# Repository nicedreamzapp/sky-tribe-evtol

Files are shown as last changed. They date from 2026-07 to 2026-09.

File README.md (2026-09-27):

# Sky Tribe — Open Amphibious Personal eVTOL
*A single-seat electric flying machine that lands on water and takes off again. Designed and built in America, given away to everyone.*

**In one sentence:** Sky Tribe is an open-source design for a one-person electric VTOL aircraft that floats, with an interactive 3D CAD viewer and runnable Node scripts that check its geometry, performance and cost.

**Stage:** design and analysis. Nothing has been built or flown yet; the first hardware step (M1, one motor on a thrust stand) is still ahead.

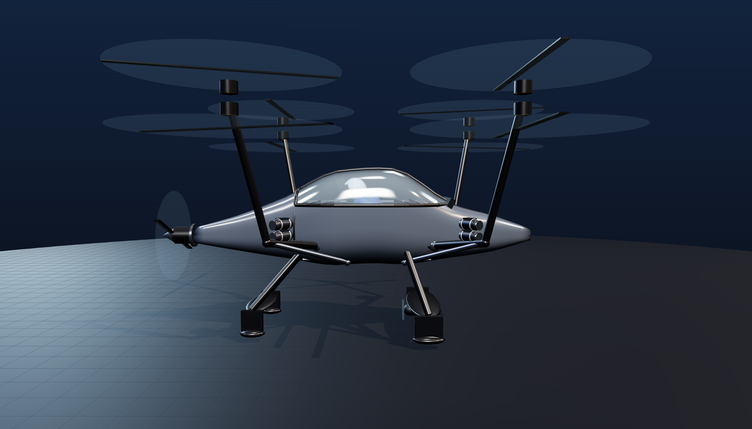
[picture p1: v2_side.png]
Sky Tribe P1 — side


> **Mission:** This project is about freedom of movement, not force. Quiet electric flight. Fewer barriers between people and places. A machine that treats the ocean as a friend — never a weapon. We build it to unite, to explore, and to give people more free will in how they move through the world.

| | |
|---|---|
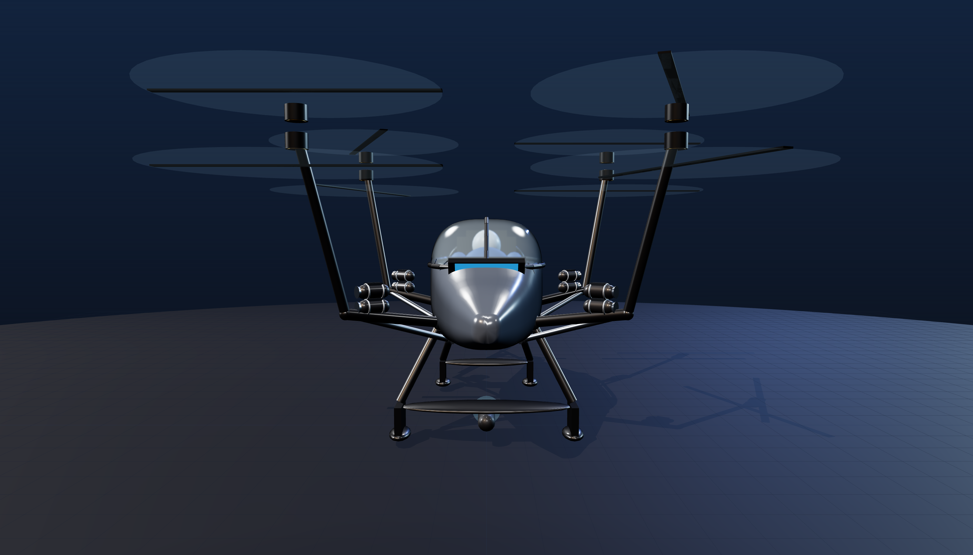
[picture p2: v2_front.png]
front
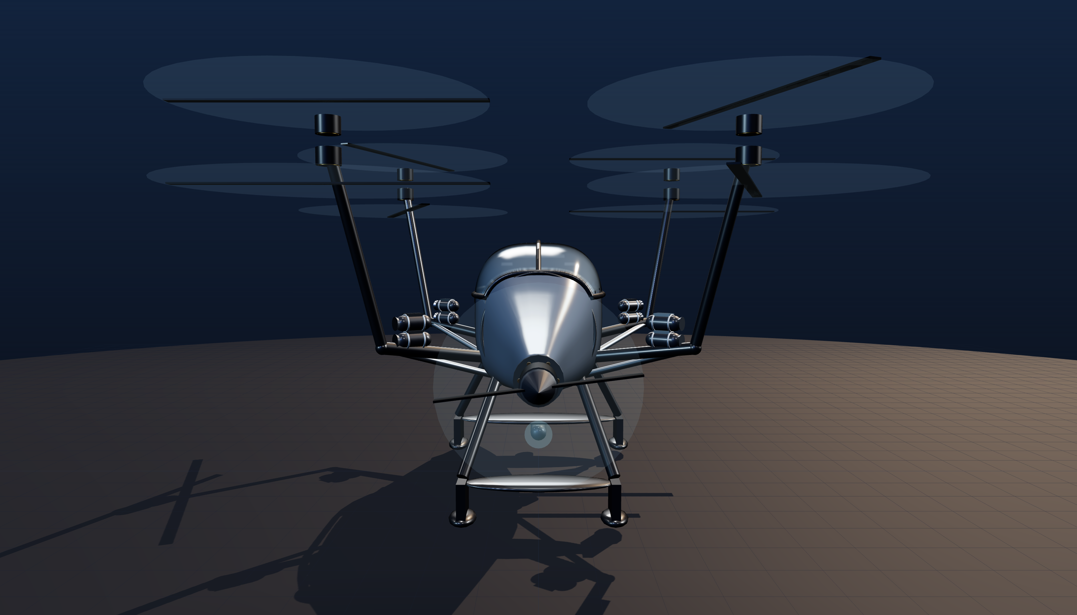
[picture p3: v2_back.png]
back
|  |  |

**Proof you can run in a minute** (Node.js only, no npm install):
```bash
node geometry_audit.mjs     # 19 clearance checks, 0 FAIL, 0 WARN
node performance_model.mjs  # hover, endurance and range for P1 and P2
node project_cost.mjs       # parts, hidden costs, whole-program total
```
Then open `sky_tribe_viewer.html` in a browser to spin the CAD.

## What I built (Matt Macosko)
- **Interactive CAD viewer:** [`sky_tribe_viewer.html`](sky_tribe_viewer.html), with P1 / P2 / P3 configs, click-a-part price and spec cards, a narrated tour (`?present=1`) and PNG export (`?shot=1`). Shortcuts: [`sky_tribe_P1_heavy.html`](sky_tribe_P1_heavy.html), [`sky_tribe_P2_light.html`](sky_tribe_P2_light.html)
- **Geometry audits:** [`geometry_audit.mjs`](geometry_audit.mjs) (+ [`geometry_audit.html`](geometry_audit.html)), [`interior_audit.mjs`](interior_audit.mjs), [`hybrid_audit.mjs`](hybrid_audit.mjs)
- **Performance model:** [`performance_model.mjs`](performance_model.mjs) (hover power, max endurance, best-range speed)
- **Hybrid genset analysis:** [`hybrid_energy_model.mjs`](hybrid_energy_model.mjs), [`hybrid_bom.mjs`](hybrid_bom.mjs)
- **Cost and build order:** [`project_cost.mjs`](project_cost.mjs), [`build_order.mjs`](build_order.mjs), [`PARTS_LIST_BOM.md`](PARTS_LIST_BOM.md)
- **Research:** five rounds in [`RESEARCH_REPORT_*.md`](RESEARCH_REPORT_2026-07-13.md), plus [`WATER_STANCE.md`](WATER_STANCE.md)
- **Design history:** OpenSCAD models [`manned_quad_v2.scad`](manned_quad_v2.scad) through [`manned_quad_v7.scad`](manned_quad_v7.scad)

Upstream: 3D rendering uses [three.js](https://threejs.org/) (loaded from a CDN). The planned flight stack is upstream [ArduPilot](https://ardupilot.org/) / [PX4](https://px4.io/); see [`CREDITS.md`](CREDITS.md).

## What this is
A fully open-source design for a **single-seat coaxial-X8 electric VTOL** — eight motors on four arms — that is sealed and buoyant so it can **land on water and take off again**, like the waterproof RC drones, scaled up to carry one person.

Everything is open: the CAD, the parts list, the flight-control approach, and the research behind every decision. No proprietary black boxes. If someone already gave their work away (open-source flight software, published physics), we build on it and give ours away too.

**Every number below is one we can defend, including the ones that hurt.**

## Two aircraft, one airframe
The weight limit was blocking everything, so we stopped letting it. Same airframe, same X8, same quick-swap battery bay — two configurations in two different legal lanes.

| | **P1 — "the fat crazy one"** | **P2 — "the low-cost lightweight one"** |
|---|---|---|
| Empty | ~176 kg | ~124 kg |
| Battery | 13 kWh · 58 kg | 5 kWh · 20 kg |
| Endurance | **11.9 min hover · 15.1 min max** | **6.4 min hover · 7.9 min max** |
| Range | ~15 miles (at 73 mph) | ~6.6 miles (at 60 mph) |
| Speed | best-range 73 mph · level cruise (pusher) | best-range 60 mph · cruises 9–13° nose-down |
| Legal lane | Experimental amateur-built (N-number, licensed pilot) | **Part 103 ultralight** — no licence, no registration |
| Purpose | The learning machine. Flies first. Weight is not a constraint. | The production seed. Built with P1's lessons. |

P1 exists so the program isn't hostage to the 254 lb limit. P2 is the machine anyone can legally fly.

## Current design
- **Propulsion:** coaxial **X8** — 8 motors, 4 arms, 2× 62" counter-rotating props per arm, ~33 kg/m² disk loading
- **Why X8:** a flat quad has **no motor-out capability** — one dead motor or ESC and it is uncontrollable. The literature is blunt about it: a single-rotor failure on a manned quad is catastrophic, quads show the highest failure rate of the configurations studied, and **at least eight rotors** is what satisfies motor-out safety. A standard hexacopter is *not* fault-tolerant either — six rotors buys nothing.
- **Structure:** central carbon spar box carries all four arms, the seat and the gear. Booms **dog-leg outboard low, then climb** — nothing crosses the canopy. Each boom is braced from *below* by a keel strut, like a braced-wing aircraft's lift strut.
- **Flight control:** DIY triple-redundant, built on open-source **ArduPilot/PX4** across 3 voting boards — not an $18k proprietary box. This is the plan; the voting code is not in this repo yet.
- **Water:** sealed buoyant hull (**650 L against 261 L displaced — 2.5× reserve**), motors high, floats then flies. Never powers up through the surface.
- **Safety:** whole-aircraft ballistic parachute (Part 103 weight-exempt)

## Honest status — what does not close yet
- **Hover draws ~52 kW at P1's 261 kg all-up**, not the ~25 kW quoted early on. That figure was for a lighter quad, ignored the 9–15% coax penalty, and quoted shaft power rather than what the battery actually pays.
- **Endurance is the real problem, not speed.** P1 flies **15 minutes** and **15 miles**; P2 flies **8 minutes** and **6.6 miles**. These are hop-across-the-bay machines, not tourers.
- **Top speed is capped by the rotors, not power.** Past roughly **67 mph** (advance ratio 0.25) the advancing blade runs out of tip margin while the retreating blade loses grip. A pusher does *not* raise that ceiling — it buys a level cruise attitude and better efficiency, nothing more.
- **A genset roughly quadruples the endurance** — 5 gallons of petrol is 172 kWh thermal ≈ 43 kWh electrical, against 13 kWh in the battery, and under Part 103 *fuel is weight-exempt while batteries are not*. That is **49 minutes of hover against 12**. It costs **+$2,500 and +34 kg**: the full system is 92 kg (engine 42, generator 7, radiator 14, buffer 10, plus rectifier, mounts, exhaust and fuel system) versus 58 kg of battery. All-up rises to 309 kg, which needs **70 kg/motor** to fly — so the genset does not dodge M1, it leans on it harder. See `hybrid_bom.mjs`.
- **Thrust-to-weight is the live risk.** At 50 kg/motor P1 is only 1.35 — and 1.18 with a motor out. It needs **60–70 kg/motor**. **M1 (thrust-standing one motor) is the gate that decides whether P1 flies at all.**
- **P2 is ~9 kg over** the 115.2 kg Part 103 limit as drawn. The carbon layup has to close that gap.
- **Foiling doesn't close.** It floats and flies off water today — that part is sound. But the water pod is under-powered for the takeoff hump (~2.2 kW needed, ~2 kW modelled) and the foil is not yet a real cambered section. Foiling is Phase 2.
- **No flight-control code, test data or hardware exists yet.** Everything here is CAD, models and research.
- Jetson ONE proves 253 lb *is* achievable, so the P2 target is real.

## What it costs — honestly
The parts list is not the project. Both numbers matter, and they are far apart.

| | |
|---|---|
| **P1 — one aircraft, parts only** | **~$46,600** (up to ~$53,800 if the motors land at U15XXL-class) |
| P2 — lighter build, smaller pack, no pusher | ~$39,600 |
| P3 — same airframe, battery swapped for the genset | ~$49,100 |
| **P1 actually flying, all in** | **~$82,600** |
| Whole program (P1 + P2 + genset conversion) | ~$139,700 |

The gap between $46,600 and $82,600 is everything a parts list quietly omits: the
thrust stand, tether rig and ballast; carbon moulds, vacuum and consumables;
machining the spar box; wiring and HV safety gear; telemetry; spares; and an
**$8,000 crash allowance**, because M2 and M3 exist precisely to break things.
Labour is $0 — it assumes you build it yourself.

**The cheapest useful thing you can do is ~$5,300**: one motor, one prop, one ESC and
a thrust stand. That is M1, and it answers whether any of this flies before the big
money moves. Vendor numbers die on the stand. See `project_cost.mjs`.

### You do not build the cockpit first
The ladder already says M2 and M3 are unmanned and ballasted — so nothing that exists
for a *person* is needed to prove the machine hovers:

| | | |
|---|---|---|
| **Step 1 — M1** | one motor on a stand | **~$5,300** |
| **Step 2 — M2/M3** | a flying platform: spar box, arms, 8 motors, props, ESCs, battery, computers, plain test skids, tether | **~$33,300** |
| **Step 3 — M4/M5** | everything a human needs: tub, canopy, seat, panel, chute, foil gear, pusher | **~$18,100** |

The cockpit, the canopy, the parachute and the hydrofoil gear are **$18,100 you can
defer** until the aircraft has already hovered thousands of times. Build the platform.
Fly it empty. Add the human last — which is exactly what the safety ladder demanded
anyway. See `build_order.mjs`.

## Safety comes before any human ever flies it
**No person goes aboard until this is proven safe** — unmanned first, then ballasted, across many loads and conditions. The build order is non-negotiable:

1. **M0** — Close the weight budget on paper
2. **M1** — Thrust-stand ONE motor. **Vendor numbers die on the stand.**
3. **M2** — Full frame, tethered unmanned hover
4. **M3** — Ballasted tethered hover, thousands of cycles
5. **M4** — Manned, tethered, over water
6. **M5** — Free flight over water

## Geometry is audited, not eyeballed
`geometry_audit.mjs` checks the whole craft numerically — every boom and strut sampled along its length against the canopy, prop and rotor clearances, the coax spacing rule, gear-to-ground, pilot sightlines and headroom, battery fit at its **actual height**, and pusher clearances.

```bash
node geometry_audit.mjs     # 19 checks, 0 FAIL, 0 WARN
```

It exists because eyeballing kept missing real defects: arms passing through the canopy glass, a battery hanging out through the belly, the pilot's feet outside the fuselage, and a cockpit sill sitting *above* the pilot's eye line.

## Repository map
| File | What it is |
|---|---|
| `sky_tribe_viewer.html` | **The live CAD.** Interactive, photoreal, click any part for its price and spec |
| `sky_tribe_P1_heavy.html` / `sky_tribe_P2_light.html` | Open the CAD locked to either configuration |
| `geometry_audit.mjs` / `geometry_audit.html` | Automated clearance + interference audit |
| `interior_audit.mjs` / `hybrid_audit.mjs` | Cockpit parts and genset hardware fit inside the skin |
| `performance_model.mjs` / `hybrid_energy_model.mjs` | Hover, endurance, range; what fuel is worth |
| `project_cost.mjs` / `build_order.mjs` / `hybrid_bom.mjs` | Cost, staged spend, genset parts and mass |
| `PARTS_LIST_BOM.md` | Bill of materials (**being refreshed for the X8**) |
| `RESEARCH_REPORT_*.md` | Five rounds of fact-checked research, adversarially verified |
| `manned_quad_v2..v7.scad` | Design history (superseded by the viewer) |

**View the CAD:** open `sky_tribe_viewer.html` in any browser — no install, no account. It needs an internet connection, because three.js loads from unpkg.
`?cfg=p1|p2|p3` picks a configuration · `?present=1` runs a narrated tour · `?shot=1` renders a PNG

## How to contribute
Anyone may use, study, modify, and share this design. Improvements that keep it open are welcome — especially the weight budget, the redundant flight-control code, water sealing at scale, and the foil section. **Test data is as valuable as design changes.** No weapons work.

## License
Open hardware and open source, chosen so it can **never be locked up**:
- **Hardware / CAD:** [CERN-OHL-S-2.0](https://ohwr.org/cern_ohl_s_v2.txt) (strongly reciprocal — derivatives stay open)
- **Software:** [GPL-3.0](https://www.gnu.org/licenses/gpl-3.0.txt)
- **Documentation / research:** [CC-BY-SA-4.0](https://creativecommons.org/licenses/by-sa/4.0/)

You are free to build one. You are not free to take it private.

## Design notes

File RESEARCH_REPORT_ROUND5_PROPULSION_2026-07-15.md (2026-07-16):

# Sky Tribe — Round 5 Research: Propulsion & Architecture (no taboos)
**Date:** 2026-07-15 · **Method:** deep-research harness, 104 agents, 22 sources fetched, 107 claims extracted, 25 verified by 3-vote adversarial panel → **24 confirmed, 1 refuted**

## The one-line verdict
**Electric multirotor is confirmed #1 — we're on the right propulsion. But the flat quad was the weakest link in the whole design, and the X8 decision (made 2026-07-15) is now literature-backed, not just instinct.**

---

## 1. Architecture — the X8 call was RIGHT (and hexa is a trap)

- **A manned flat quad is ruled out by the numbers** (DLR HorizonUAM, verified verbatim): single-rotor failure on a quad is *catastrophic* — partial lift loss is uncontrollable for a passenger vehicle. Quads showed the **highest catastrophic failure rate of four VTOL configs studied (~8×10⁻⁴/hr)**. Studies conclude **at least eight rotors (coax X8 or flat octo)** is what actually satisfies motor-out safety. Motor-out on a quad-shaped layout also demands ~2× installed power (each corner sized for ≥50% of hover thrust). *Caveat: those reliability budgets are air-taxi certification stringency, way beyond Part 103 — but the physics of "dead corner = uncontrollable" applies to any manned quad.*
- **Hexacopter is NOT a middle path** (Du/Quan, AIAA JGCD 2015, verified): the standard alternating-spin hexa is **uncontrollable after ANY single rotor failure** despite having six motors. Even the special fault-tolerant spin arrangement still has two unsurvivable rotor positions. **Motor-out survival depends on spin-direction geometry, not rotor count.** Six motors ≠ redundancy.

## 2. Honest correction: the coax penalty is BIGGER than we assumed

We budgeted ~5–8% for the X8's stacked-rotor loss. **The verified number is ~9–15% for an optimized design** (NASA Ames CFD: a coax pair gives 182% of one rotor, not 200%; bench tests: ~14% thrust-per-watt penalty, up to 19–23% on the worst metric). Key details:
- The loss falls almost entirely on the **lower rotor** (~64% of its isolated thrust — it drinks the top rotor's downwash).
- A **stopped lower rotor adds ~180 gf of backwash drag** — relevant to motor-out thrust math.
- Mitigations: **graded/higher pitch on the lower prop**, and the penalty **shrinks at higher disk loading**.
- Literature is admittedly messy at small scale (13–28" props); direction transfers to our 54" props, exact percentages don't.

**Design rules that survived verification:**
- **Coax vertical spacing ≥ 0.25 rotor diameters** — thrust is nearly insensitive to spacing above that; below it you pay. For 54" props that's ≥ ~343 mm between the two prop planes. *(CAD updated to 350 mm same day.)*
- **Small prop-disc overlap (0–20%) with vertical offset is harmless to slightly beneficial** (+1–2% thrust at constant power) — arm geometry has slack if we ever tighten the footprint.
- The NASA Ames / Army AFDD hover-chamber dataset (coax/tandem/tilt vs equal-solidity single rotors) is the apples-to-apples benchmark to design against.

**BOM implication:** X8 needs ~9–15% more battery for equal endurance vs the quad, not 5–8%. Fold into the next BOM refresh.

## 3. Propulsion ranking (verified where possible)

1. **Distributed electric multirotor — CONFIRMED #1.** Nothing that survived verification beats it at 25 kW / Part 103 scale. We're using it.
2. **Series-hybrid genset — right idea, HARDWARE GAP FOUND.** The Part 103 fuel exemption genuinely favors fuel over batteries (14 CFR 103.1 verified: fuel excluded, 5 US gal cap, batteries count). **But no off-the-shelf genset fits our ~25–30 kW floor in 2026:**
   - Pegasus GE70: **4 kW peak / 3.5 kg** — drone-scale, 6–9× too small, and it's Pegasus's *largest* unit.
   - Turbotech TG-R90 turbogenerator: **85 kW / 64 kg dry**, multi-fuel incl. H2 (bench-demo'd w/ Safran 2024), flight-proven on experimental eVTOLs — but 3× oversized and eats 56% of our entire empty-weight budget.
   - **The 20–40 kW middle is an empty market in 2026.** Options: recheck for new entrants before the hybrid trade study; consider paralleling smaller units; or accept the 1-hr config waits for the market to fill in.
3. **Micro-turbine direct drive / H2 fuel cells / everything else** — nothing at our scale survived verification this round (see coverage caveats).

## 4. Exotics — the physics gate held

| Concept | Verdict | Why |
|---|---|---|
| EHD / ionic wind hover | **CLOSED** | Verified trade-off (MIT/Barrett, Proc. R. Soc. A): thrust density and efficiency trade against each other — the famous ~100 N/kW exists only at ~1–3 N/m², orders of magnitude below the ~200–500 N/m² a hovering manned craft needs. Newer ducted multi-stage work pushed density ~10× (our older "750 m² needed" number was REFUTED — killed 1-2 in verification) but it's still tens of N/m². Closed for hover; interesting for near-silent fixed-wing cruise someday. |
| Static maglev / "hover on Earth's field" | **CLOSED** | Earnshaw's theorem: no static arrangement of magnets/charges can stably levitate. Earth's ~50 µT field has nothing usable to push against for free flight. |
| Beamed power hover | **FRONTIER, far off** | Best 2025 demo (DARPA POWER/PRAD): **800 W at 8.6 km for 30 seconds** — a record, and still ~30× short of our hover floor, delivered for 1/120th of our minimum flight. Watch, don't build. |
| Tesla-lineage | Same as beamed power — resonant/wireless transmission is his real legacy and it's the row above. No verified antigravity anything. |

## 5. Coverage caveats (what this round did NOT confirm)
Nothing survived verification on: real-program rationales (Jetson ONE 8-motor layout, LIFT Hexa's 18 rotors — extracted but not confirmed), fuselage aero critique (fineness ratio, tail cone, spray ingestion), H2 stacks at our scale, variable-pitch/rim-driven/cycloidal rotors, flywheels, ground effect. **Treat those as open, not settled.** Two claims passed 2-1 (coax equal-throttle loss; GE70 power density) — verified against primaries but carry metric-mismatch caveats.

## 6. Open questions for Round 6
1. Actual coax penalty at OUR scale (62"→54" props, our disk loading, graded-pitch lower rotors) — full-scale test or validated CFD decides 9% vs 15%.
2. Can the 115.2 kg budget absorb the X8 conversion + 9–15% bigger battery? (Two-prototype program partially defuses this — P1 heavy doesn't care.)
3. Does ANY 20–40 kW genset ship in 2026? Recheck before committing the hybrid trade study.
4. The unverified areas above need their own pass — especially water ops (spray ingestion at our rotor height) before M5.

## Key sources (all fetched & verified 2026-07-15)
- DLR HorizonUAM powertrain reliability: arxiv.org/pdf/2309.10631
- Hexa controllability (Du/Quan): arxiv.org/pdf/1403.5986
- NASA Ames coax CFD (Yoon 2017): ntrs.nasa.gov/api/citations/20170000654
- Rutgers coax experiments (Aerospace 2022): mdpi.com/2226-4310/9/8/452
- Overlap/offset (Weishaupl & Prior): eprints.soton.ac.uk/433170
- Pegasus GE70: pegasusaero.ca/ge70 · Turbotech TG-R90: turbotech-aero.com/solutions
- EHD trade-off (Masuyama & Barrett): royalsocietypublishing.org (Proc. R. Soc. A 2015)
- DARPA power-beaming record: darpa.mil/news/2025 · Earnshaw: math.ucr.edu/home/baez
- Part 103 text: ecfr.gov 14 CFR 103 · FAA: faa.gov/media/13046

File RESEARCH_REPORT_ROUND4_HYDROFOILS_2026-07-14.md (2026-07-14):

# Round 4 — Hydrofoil Landing Gear (foil = skid)
**Date:** July 14, 2026 · 101-agent sweep, 3-vote verification. Permanent reference for sizing our foils.

## Bottom line
Foiling a ~240 kg single-seat amphibian is **physically feasible with real prior art.** The smart choice for our weight is **fixed inverted-V surface-piercing foils** (self-balancing, no computer needed). The hard part isn't lift — it's the **takeoff "hump"** (needs ~3–4× the cruise power). And the one piece nobody has proven is **exactly your idea**: a foil strut that ends in a skid foot for hard-ground landing. That's our open ground.

## The sizing math (verified)
Lift: **L = ½ · ρ · V² · S · C_L** (ρ_water = 1000, so water makes huge lift). Worked check: 0.12 m² at C_L 0.60 and 6 m/s (~12 knots) in fresh water = **~1,300 N ≈ 132 kg**. So to lift our **240 kg we need ~0.15–0.20 m² of total foil area** at ~15 knots — small.
- **Real anchor:** a 650 kg ultralight seaplane (SEAGULL, peer-reviewed) used 0.2 m²/foil at 15 knots. Scaled to us ≈ **~0.07–0.10 m² per foil** (two foils). Foils cut its liftoff speed from 44 → ~20 knots and unloaded the hull by ~80%.
- **Minimum foiling speed: ~15–18 knots (17–21 mph).** Below that, the wings don't make enough lift and you sit as a hull.

## How it balances — this answers your question directly
Two proven paths:
1. **Fixed inverted-V surface-piercing foils (LISA Akoya "Seafoils")** — **self-stabilizing with ZERO pilot input and no controller.** As the craft rises, less foil is in the water, so lift drops automatically — it self-levels. Flew at Oshkosh 2012. **This is the best architecture for our Part 103 weight budget** — no actuators, no computer loop, lightest.
2. **Active fully-submerged foils (Candela C-8, Artemis ferries, foiling Moths)** — 10+ sensors adjust flaps ~100×/sec. Smoother and more efficient, but *requires* the control loop (submerged foils are unstable without it). The good news: it's cheap to build — a PID loop on accelerometers driving servos, which **an off-the-shelf drone flight controller runs already** (our triple-redundant brain can do it).

**Recommendation:** start with fixed V-foils (simple, self-stable, light); upgrade to active later if we want cruise efficiency.

## The real constraint: the takeoff hump
- **Candela C-8: 55 kW to take off, but only 16 kW to sustain foiling at 20 knots (~3.4×).** The whole water-motor sizing is driven by getting *over* the hump, not cruising.
- **Water motors (saltwater-ready, off-the-shelf):** Torqeedo Cruise 3.0 (3 kW, ~64 kg *static* thrust, IPx9K) or Lift eFoil motors (2.2 kWh, ~90 min). **Caveat:** that 64 kg is *static* thrust and collapses at 15–20 mph — **one pod is likely not enough to punch through our takeoff hump.** Plan for two, or a bigger motor, or use the lift-props (airboat mode) to help accelerate onto the foils.

## Retraction & the foil-as-skid (your idea)
- **Retractable foils are solved** — patents (screw-shaft stow into a wing slot), SEAGULL L-foils retract into floats, Artemis retractable high-aspect foils. Low mass, proven.
- **BUT: no source anywhere validates a foil strut ending in a ski/skid foot for hard-ground landing.** That specific dual-purpose part — foil in water, landing foot on ground — **is unproven prior art.** It's genuinely novel. It's also the thing we most need to test (does a foil-shaped foot survive a hard landing *and* work as a foil?).

## Honest caveats (the catches)
- **Weight is the real risk.** The "~1% of AUW" foil-mass figure comes from a 5,600 kg amphibian and does NOT scale down — hardware has a mass floor (struts, retract gear, motor). At 240 kg with a Part 103 254-lb limit already 47 kg over, the foil system's real mass could be the thing that sinks the budget.
- **Foiling's payoff is smoother/faster water, not a dramatic leap.** A Twin Otter study saw only ~3.5% takeoff gain from foils. **Just floating remains a totally legitimate choice** — foils are a "nice, fast, smooth" upgrade, not a necessity.
- **Nobody has built a sustained-cruise foiling personal aircraft** — only takeoff-assist foils (Akoya). We'd be early.

## What this means for our CAD/design
- Size the foils at **~0.15–0.20 m² total** (two foils, ~0.08 m² each) — small, which is why they can double as compact skid feet.
- Go **fixed inverted-V surface-piercing** first — self-balancing answers the "how does it stay level" worry with zero electronics.
- Budget **two water thrusters or one bigger one** for the takeoff hump; consider using the lift-props to help accelerate.
- **Prototype the foil-foot** early — it's the novel, unproven piece and the whole dual-purpose concept rides on it.
- Keep foiling as a **Phase-2 upgrade** — floating works today; foiling makes it fast and smooth later.

*Sources: SEAGULL (Springer 2021), MDPI Aerospace 2021 (amphibian foils), LISA Akoya, Candela, Artemis Technologies, Torqeedo, Lift Foils, US Patent 2,997,260, foils.org.*

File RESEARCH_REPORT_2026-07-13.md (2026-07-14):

# Manned eVTOL Industry — Deep Research Report
**Date:** July 13, 2026 · **Method:** 106-agent research workflow — 5 search angles, 24 sources fetched, 119 claims extracted, top 25 adversarially verified by 3-vote panels (22 confirmed, 3 refuted)

## Bottom line for Matt

The industry has split in two. The winged air-taxi lane (Joby, Archer, Vertical) is a multi-billion-dollar certification war with **zero US commercial passenger flights to date** — closed to small teams. But the **single-seat Part 103 ultralight lane is demonstrably open**: Jetson ONE is sold out through 2027 at $148K with a ~$100M order book and **no FAA certification of any kind**. Your concept lives in the open lane.

## Verified findings (all survived 3-0 adversarial verification unless noted)

### 1. Part 103 is THE path — and the 254 lb line is everything
14 CFR Part 103: no airworthiness certificate, no pilot certificate, no medical, no registration. Hard limits: **empty weight under 254 lb / 115.2 kg (batteries COUNT toward it)**, single occupant, max 55 kt, recreation/sport only, no commercial ops. A **ballistic parachute is EXCLUDED from the weight count** (deployable safety device) — free safety margin. Floats are also excluded — huge for the amphibious concept. This is exactly how Jetson, Pivotal, Lift Hexa, and Ryse Recon all sell today. *(Source: current eCFR text, verified July 2026)*

### 2. MOSAIC opens the growth path — 11 days from now
MOSAIC final rule (published July 24, 2025): LSA certification provisions take effect **July 24, 2026**. It expands light-sport to rotorcraft and powered-lift (2 seats max) with electric propulsion. Consensus standards for powered-lift don't exist yet, so it's prospective — but it's the ladder from Part 103 toy → certificated 2-seat product. *(FAA.gov + Federal Register 90 FR 35034)*

### 3. The giants are still pre-revenue
As of May 2026 **no eVTOL company has flown a paying passenger in the US**. Joby: ~82% through the final certification stage, first FAA-conforming aircraft flying, ~$2.6B cash, Toyota alone has invested $894M. Archer: finished Phase 3 April 2026, ~$2B raised. Vertical: up to $850M secured, targeting 2028 EASA cert. eVTOL stocks broadly down in 2026.

### 4. What killed the failures (the cautionary tale)
- **Lilium**: ~$1.5B raised since 2016-17 → insolvent Oct 2024 when Germany refused a €50M guarantee; rescue buyer pledged €200M, delivered €5M, dead Feb 2025.
- **Volocopter**: ~$544M raised, one of the lowest burn rates in the industry, ~75% through EASA audits → insolvent Dec 26, 2024. *(2-1 vote on one element)*
- **Lesson:** even frugal, certification-advanced players die when capital markets close before revenue. Never build a business that needs type certification before dollar one of income.

### 5. Demand in the personal niche is real
Jetson ONE: **$148,000** ($8K non-refundable deposit), production sold out 2026 AND 2027, earliest new delivery 2028, 650+ units / ~$100M order book, predominantly US buyers. Sell-before-certify works in this category. *(Jetson order page fetched live July 2026)*

### 6. Your exact propulsion is off the shelf
T-Motor U15XXL KV29: **$1,999/motor** (~$8K for four before props/ESCs), marketed by T-Motor for "Manned Aircraft & 100kg Heavy-Lift Drone," 12–24S. Four give your 180–220 kg AUW a thrust-to-weight of ~1.8–2.2, hover near half throttle. Caveat: 100 kg is peak thrust and a vendor number.

### 7. Certifiable flight control is buyable, not a science project
Embention **Veronte 4x**: three internal autopilot cores + optional fourth dissimilar core, voting arbiter designed with no single point of failure, DO-178C/DO-254 DAL B evidence (DAL A ongoing), DO-160G tested, ETSO-C198 in progress with an EASA-approved cert basis (a first for eVTOL flight controls). Explicitly marketed for piloted eVTOL fly-by-wire. A small team buys its certification paper trail instead of writing it.

### 8. The physics verdict (peer-reviewed)
Multirotors are the MOST efficient config in hover and the WORST in cruise/range. At directly comparable scale (EHang 184: 260 kg, 14.4 kWh): ~47 kW hover, **~20.5 min endurance**, ~42 km practical range vs 107 km (lift+cruise) and 203 km (vectored jet). **Plan on 15–20 minutes hover as the realistic ceiling on current Li-ion.** Endurance scales roughly linearly with pack energy density (that analysis used 2019-era 157 Wh/kg; 2026 cells are better). The product must be a short-hop recreational/experience vehicle, not a range play. *(Bacchini & Cestino, Aerospace 2019, math independently recomputed by verifiers)*

### 9. Viability synthesis (medium confidence — judgment, not verified fact)
The lane for a small AI-assisted team: (a) hit 254 lb empty at higher useful load than Jetson, (b) differentiate on flight-control software / redundancy on top of COTS autopilots, (c) use MOSAIC LSA as the growth route to 2-seat certificated products. The physics constraint cuts both ways — the same short endurance that makes Part 103 feasible caps the product at a ~20-minute experience machine. **The amphibious angle (Matt's) is untouched by every competitor examined.**

## Refuted during verification (do not cite)
Three claims from evtolindex.org's certification tracker were killed 0-3 (stale data), including its EHang and Joby status entries.

## Known gaps (flagged honestly by the verify pass)
- **EHang/China**: no EHang claims survived verification — its real CAAC status/order book is uncharacterized here (they are flying passengers in China per unverified sources).
- **Pivotal, Lift Hexa, Ryse Recon**: pricing/delivery claims didn't survive; only their Part 103 positioning is confirmed. (Unverified fetches saw: Pivotal Helix $190K–$260K; Ryse Recon ~$150K, farm-market angle.)
- **2026 battery state of the art** and ballistic-chute vendors: not verified this round — queued as the next research question.

## Open questions for round 2
1. EHang's actual verified certification + passenger ops status.
2. Best 2026 aviation-suitable pack (Wh/kg, C-rate, thermal runaway containment) — Amprius/Sion/solid-state — and what it does to the 20-min ceiling.
3. Can a 4× U15XXL quad + pilot seat + 24S pack + frame close under 254 lb empty? Full mass budget. (Jetson does it with 8 smaller motors.)
4. Lift's pay-per-flight and Ryse's farm angle vs direct $148K sales — better wedge?

## Key sources
eCFR Part 103 · FAA MOSAIC page + Federal Register 2025-13972 · CNBC 2026-05-29 · Joby Q1 2026 shareholder letter (SEC) · jetson.com/order (live) · store.tmotor.com (live) · embention.com · Bacchini & Cestino, *Aerospace* 2019 (DOI 10.3390/aerospace6030026) · evtol.news · autoevolution · Aviation Week

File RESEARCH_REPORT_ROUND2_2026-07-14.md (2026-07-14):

# Round 2 — Water Tech · Racing Science · Batteries · Defense
**Date:** July 14, 2026 · **Method:** 106-agent sweep, 3-vote adversarial verification per claim. Permanent project reference — lives with the CAD.

## The four answers in one breath
Water landing is proven engineering (two-tier sealing, float-clear-then-launch). Racing speed does NOT scale — a manned quad cruises 50–65 mph no matter how much power you install. The Part 103 weight budget **demonstrably closes** (Jetson ONE = 253 lb with batteries). And the defense market is a documented ladder that starts at a $75k SBIR grant.

## 1. Water-capable drone technology (all verified 3-0)
- **The two-tier rule:** motors run WET with corrosion-resistant coatings; everything sensitive (avionics, battery) lives in sealed dry compartments. Don't waterproof every component — split wet-side/dry-side. JHU-APL's CRACUNS coated motors survived **2 months submerged in saltwater** with zero corrosion, running while submerged.
- **SwellPro SplashDrone 4** (best commercial water drone): IP67 body + coated ordinary hobby motors/ESCs — the coating is the magic, not exotic parts. Its **PowerFlip self-righting is active motor thrust** (3-second stick command), not passive shape — a capsized craft floats stable inverted until commanded to flip.
- **Never power through the water surface:** rotors see ~12–15% thrust fluctuation at the air-water interface. Every proven design **floats fully clear first, then takes off entirely in air** (Loon Copter pumps ballast, floats up, then lifts). Our sealed-hull + rotors-above-deck layout is exactly the validated architecture.
- **TJ-FlyingFish** (ICRA 2023, peer-reviewed): true air/water hybrid using T-Motor hobby parts — tilting motor pods with a 12:1 gear shift for underwater torque. Proof the dual-medium concept is real — at 1.6 kg. **Caveat that gates everything:** all of this is proven at 1–3 kg scale; at U15XXL scale, coating durability and bearing life must be re-proven on OUR thrust stand.
- **Refuted (do not repeat):** CRACUNS "launches from depth" (overstated) and the Naviator stacked-rotor water-exit story (0-3) — re-research before citing.

## 2. Racing-drone science, scaled (verified 3-0)
- **The hard ceiling:** peer-reviewed rotorcraft analysis puts a wingless multirotor's efficient cruise at **~56 mph**, with the power curve going near-vertical past ~100 mph (>300 kW). Our realistic cruise: **50–65 mph regardless of installed power.** The 2:1 thrust-to-weight buys climb authority and control crispness — the racing *feel* — not top speed. Speed beyond that requires wings, full stop.
- **The prop vindication:** hover power per kg scales with √(disk loading). VoloCity (12 kg/m²) needs 116 kW; Joby (55 kg/m²) needs 451 kW. Ours: **~32 kg/m²** — the 62" props are the single best decision in the design.
- What does transfer from racing: stiff unibody structure, motor thermal design, high control bandwidth, the tilted-forward cruise attitude (shape the tub for ~15° nose-down).

## 3. Weight & batteries — the budget CLOSES (Jetson 3-0; battery claims 2-1, treat as provisional)
- **Jetson ONE: 115 kg (253 lb) WITH batteries** — under the limit by one pound. Split: **~55 kg airframe** (aluminum spaceframe, 8 motors) + **~60 kg high-discharge Li-ion**, 20 min, 63 mph (software-limited). Our 4-motor carbon design has a proven-feasible target to beat.
- **Purchasable 2026 packs:** high-discharge Li-ion ~250–300 Wh/kg pack-level; Amprius silicon-anode up to 450 Wh/kg cell (500 verified third-party). A 14 kWh pack ≈ **55–70 kg** today.
- **Sion Licerion lithium-metal >500 Wh/kg: NOT purchasable yet** — first shipments Q3/late 2026, rechargeable version Q2 2027 (2-1 votes, company-sourced, slip-prone). Design for today's cells; treat next-gen as an upgrade path, not a dependency.
- **Unresolved (round 3+):** thermal-runaway containment architecture and its weight at 14 kWh; Pivotal BlackFly's carbon+amphibious weight breakdown (the closest analog to us — worth its own dig).

## 4. Defense — a documented ladder, not a fantasy (verified 3-0)
- Archer's actual path: two 2021 STTR awards totaling **$298k** → $745k Phase II (2022) → **$32M STRATFI** (2023) → contracts worth up to **$142M**, first manned Midnight delivered to USAF Edwards AFB August 2024. DoD buys *data, test reports, training, and services* — not just aircraft.
- **A small builder's first rung: SBIR/STTR Phase I, $75k–350k.** Note: Archer entered with a *manned* aircraft data package; the "unmanned variant first" hypothesis wasn't confirmed. Dollar ceilings ("up to $142M") ≠ obligated funds.

## What this means for OUR design (mentor synthesis)
1. The v5/v6 layout (sealed tub, rotors above deck, land-on-water) is the textbook-correct architecture — validated, not just cool.
2. Chase Jetson's 55 kg airframe with 4 big motors + carbon instead of 8 motors + aluminum. The weight war is winnable.
3. Sell the *feel* of racing (instant response, crisp control, 60 mph low over the water), never promise racing speed.
4. When ready for revenue diversification: file an SBIR Phase I. It's a $75k door that Archer walked through.
5. First hardware milestone unchanged and now better-justified: **thrust-stand one U15XXL, wet and dry.** The whole scale-gap caveat collapses into that one test rig.

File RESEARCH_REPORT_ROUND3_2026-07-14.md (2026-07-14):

# Round 3 — Propulsion & Energy Frontier
**Date:** July 14, 2026 · **Method:** 105-agent sweep, 3-vote adversarial verification. 23 claims confirmed. (Synthesis step hit a model rate limit; findings below are the verified raw claims.) Permanent engineering reference — what's PROVEN, what's promising, what's pseudoscience.

## THE HEADLINE — the legal loophole is real and it may win the weight war
**FAA Office of the Chief Counsel (verified 3-0):** under Part 103, **usable fuel is EXCLUDED from the 254 lb empty weight, but batteries COUNT.** The reasoning: empty weight includes only airframe, engines, permanent equipment, and *unusable* fuel; usable fuel is an allowance excluded from the number — but batteries "remain installed and keep virtually the same weight when depleted," so they count in full.

**What this means for us:** our 58 kg battery is the reason we're 47 kg overweight. A **hybrid gasoline genset** feeding the electric motors, with only a small battery for takeoff/landing peaks, could move most of that mass *out* of the counted empty weight — because up to **5 US gallons of gasoline (~14 kg, ~165 kWh chemical) doesn't count.** This is the single most promising path to closing the Part 103 weight budget AND jumping from ~20 min to potentially hours of endurance.

## 1. Hybrid gensets — proven, buyable, honest numbers (all 3-0)
- **Pegasus GE70:** 4 kW peak at 3.5 kg = **1.14 kW/kg** (best small 2-stroke benchmark).
- **Foxtech NOVA-2000:** 1.8 kW continuous / 2 kW peak, 48 V, 4 kg unit = ~0.45 kW/kg.
- **Efficiency penalty (real):** ~750 g/kWh fuel burn — ~3× worse than big aviation piston engines. Gasoline's ~12 kWh/kg becomes only **~1.3 kWh of electricity per kg of fuel** in a small 2-stroke. Still crushes batteries: 5 gal ≈ 14 kg fuel → ~18 kWh electric delivered, vs our 14 kWh / 58 kg battery.
- **Proven endurance:** hybrid drones fly **hours** vs tens of minutes — Foxtech claims ~5 h max, ~1 h on a DJI M600 with just 2 L. But those are 18–21 kg drones; scaling a ~25 kW genset to lift a person is unproven and brings **noise, vibration, cooling, and fire** penalties a pure-electric craft doesn't have.
- **Honest read:** a genset that continuously makes our full ~25 kW hover load at 1 kW/kg would weigh ~25 kg + fuel — heavier than ideal, but if it moves mass off the *counted* weight, it can still win the Part 103 math. Worth a serious trade study; NOT worth abandoning the clean simplicity of battery-electric until the numbers are run on OUR craft.

## 2. Hydrogen — powerful but not at our scale yet (3-0)
- **Joby's LH2 demonstrator flew 523 miles**, landed with 10% fuel — 3–5× the range of the same airframe on batteries. Uses a 40 kg **liquid**-hydrogen tank (not compressed), fuel-cell + small battery hybrid (battery only for takeoff/landing peaks).
- **But:** best flying fuel-cell hardware is ZeroAvia's 2.5 kW/kg (cell level); >3 kW/kg system is a *2025 target*, not shipping. Intelligent Energy's smallest aviation stack is ~200 kW — 8× our need. LH2 tanks carry a severe mass penalty (need 35–40% fuel-system efficiency to compete; best tanks reach 65–70%). **Verdict: hydrogen is real and the long-term winner for range, but there is no off-the-shelf ~25 kW stack for a one-person craft in 2026.** Revisit in a few years.

## 3–6. The exotic frontier — where the physics gate matters
*(Full details in the raw claims; these are the disciplined conclusions.)*
- **Beamed power (laser/microwave):** demonstrated only at small kW over short/fixed distances; needs a ground station and a clear beam — useless for a free-roaming personal aircraft. Not a path.
- **Solar:** disc loading kills it — a quad's rotors need far more power per m² than sunlight (~1 kW/m²) can supply. Solar flies featherweight high-altitude gliders (Zephyr), never a hovering person-carrier.
- **Ionic/EHD propulsion (MIT ion plane):** real but thrust density is thousands of times too low to hover 250 kg. Physics, not engineering, forbids it at our scale.
- **Refuted pseudoscience — cite and dismiss:** EmDrive (German precision tests showed the "thrust" was measurement artifact — zero real thrust), Mach-effect thrusters (unreplicated), "antigravity" claims (no peer-reviewed support). **These violate conservation of momentum. We never spend a dollar or an hour on them.**

## 7. The hard floor no invention can beat
Actuator-disc physics sets a **minimum hover power** for lifting 250 kg on four ~1.6 m props — roughly **25 kW** for our craft. No motor, fuel, or "new energy" can go below the momentum-theory floor; it's set by air, mass, and disc area alone. Bigger discs are the only lever (why the 62" props matter). Every propulsion choice is just a different way to *feed* that ~25 kW — battery, genset, or fuel cell. The question is never "beat the floor," it's "carry enough energy to feed the floor for long enough at the lowest counted weight." **Today that answer is: battery for simplicity now, hybrid genset as the weight-and-endurance play to study next.**

## Action items this round created
1. **Run the hybrid-genset trade study on OUR craft** — does moving battery mass into uncounted fuel close the 47 kg gap? (High priority — this is the loophole.)
2. Keep hydrogen on the watch list; re-check fuel-cell specific power yearly.
3. Physics-gate is now documented: beamed/solar/ionic/exotic are closed at our scale — don't revisit without new peer-reviewed evidence.

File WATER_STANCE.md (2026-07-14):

# Buoyancy & Water Stance
**Date:** 2026-07-14 · How the sealed craft floats. Toggle "water mode" in `sky_tribe_viewer.html` to see the waterline.

## The physics (Archimedes)
A floating body sinks until it pushes aside a weight of water equal to its own weight. Fresh water = 1 kg per liter, so:

| Case | Weight | Water it must displace |
|---|---|---|
| Empty | ~156 kg | ~156 L |
| With 85 kg pilot | ~241 kg | ~241 L |
| Pilot + 20 kg cargo | ~261 kg | ~261 L |

## The hull's buoyancy budget
The sealed lower hull (belly + cabin tub, waterproofed) encloses roughly **~650 L** of watertight volume. It only needs to submerge ~241 L to float with a pilot aboard.

- **Reserve buoyancy ≈ 650 / 241 ≈ 2.7×.** It floats HIGH, not swamped.
- **Waterline sits ~20 cm up from the bottom of the belly** — roughly at the base of the cockpit coaming.
- **The cabin, seat, pilot, battery, and avionics all stay above the waterline and dry** (and the hull is sealed anyway).
- **The landing skids hang below the surface** — they're underwater when floating, which is fine.

## Will it tip over?
No, and here's why:
- **Wide beam** (~0.9 m) gives a broad footprint on the water — high initial stability, like a jet-ski or pontoon hull.
- **Low center of gravity** — the ~58 kg battery sits at the keel, well below the waterline, acting like ballast.
- CG below the center of buoyancy + wide beam = it self-levels and resists roll.

## Sealing philosophy (two-tier — from the water-drone research)
- **Fully sealed & dry:** the whole cabin area — pilot, seat, battery, the three flight computers, all wiring. Nothing in here ever touches water.
- **Allowed to get wet:** the motors (brushless motors run wet fine with a corrosion coating — proven 2 months submerged in saltwater by JHU-APL), the skids, and the outer lower hull. These are designed to be splashed.
- So water can touch the *outside* and the *motors*; it can never reach the cabin.

## Propel on water: blades-in-water vs blades-in-air — which is faster?
**Blades in AIR (airboat mode) wins — it's faster AND safer.** Here's the honest physics:
- Aircraft propellers are *air* propellers. Water is ~800× denser than air. Dip a spinning aircraft prop into water and it **cavitates, stalls, loses most of its thrust, and risks shattering** — it's a terrible water propeller and a real damage risk.
- **Airboat mode** keeps the props in the air (where they're efficient), tilts the craft a few degrees, and pushes air backward to glide across the surface — exactly how Everglades fan-boats work. Same props, no water contact, no damage. This is the faster, proven method.
- There's also a geometry reality: with 2.7× reserve buoyancy the craft floats HIGH, so the blades (1.4 m up) sit well above the water anyway. To dip them you'd have to nearly swamp it.
- **If we ever want serious water speed,** the right tool is a small dedicated underwater thruster or water-jet (most efficient *in* water) as a bolt-on — not the lift props. But for "scoot across the bay," airboat mode is the answer and costs zero extra hardware.

**Verdict:** propel from the air with the blades above the water. Never drive the lift props into the water.

## Honest caveats
- These are **estimates from the current CAD volume**, not a measured hull. The real number comes from a displacement test of the actual molded hull (drop it in water, mark the line, weigh it).
- 2.7× reserve is comfortable; even a partial breach still floats.
- This is *floating stability*, not *takeoff-from-water*. Matt's current call: waterproof + floats if it lands on water, but not a boat that powers around. Taking off from the surface is a separate capability we can add later (rotors are already mounted high enough to clear spray).

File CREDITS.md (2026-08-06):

# 🙏 Credits

None of this starts from scratch. Here's whose work this is built on.

| Project | What it does here | By |
|---|---|---|
| 🛩️ [ArduPilot](https://ardupilot.org/) | Flight control firmware the design targets | The ArduPilot project |
| 🛰️ [PX4](https://px4.io/) | The alternative flight stack | The PX4 / Dronecode community |

---

If your work is listed here and you'd like the wording changed, or if something's
missing, open an issue and I'll fix it.

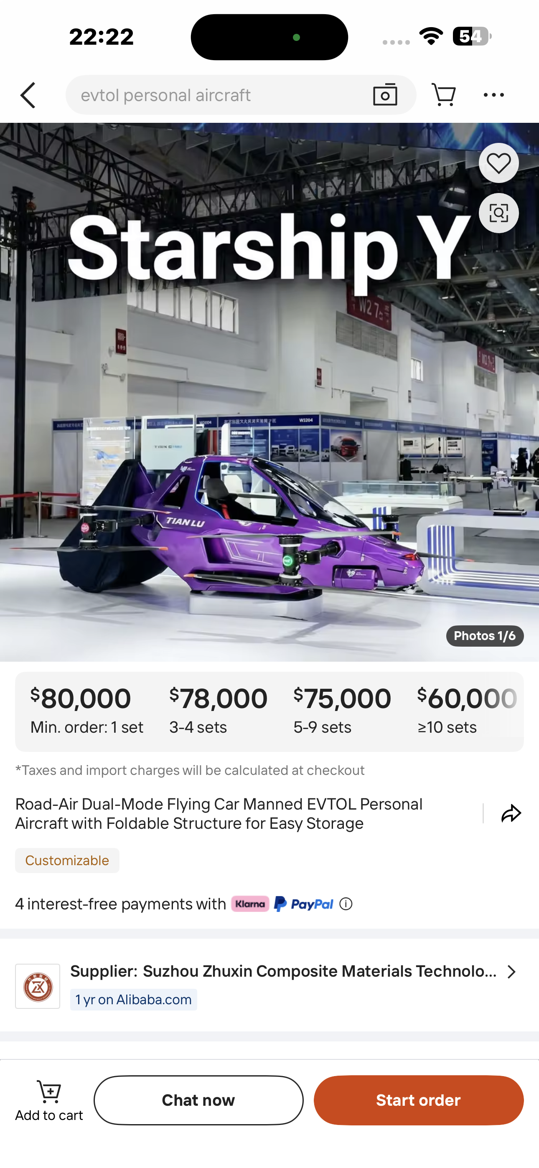
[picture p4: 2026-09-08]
Road-Air Dual-Mode Flying Car Manned EVTOL Personal Aircraft with Foldable Structure for Easy Storage.png

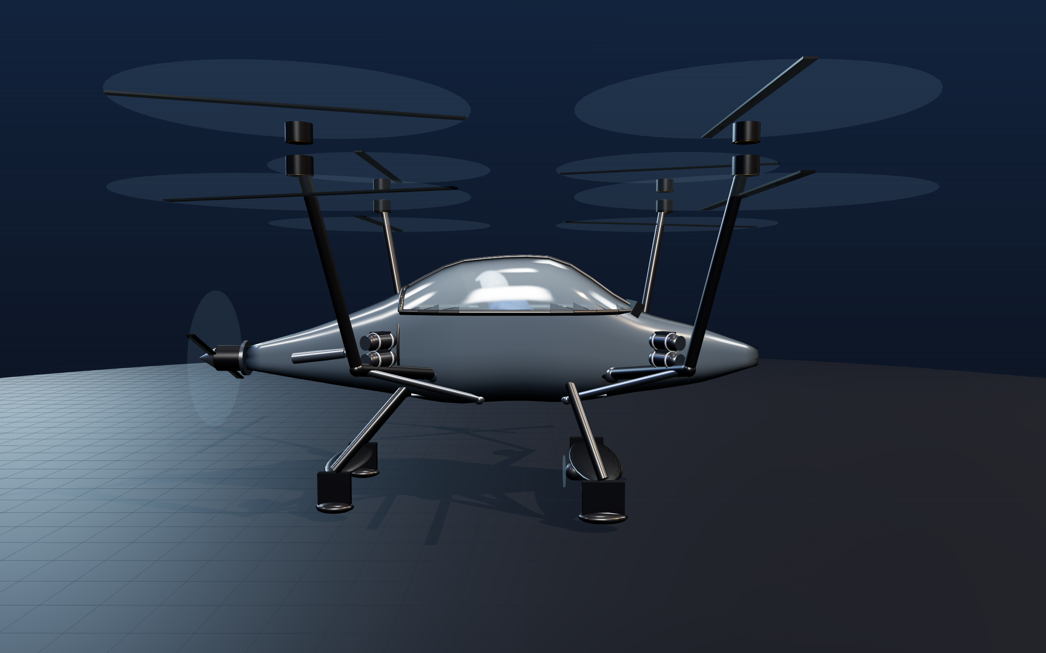
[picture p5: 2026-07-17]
p3_side.png

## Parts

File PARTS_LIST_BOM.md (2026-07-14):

# Sky Tribe Quad — Bill of Materials (v7 realistic build)
**Date:** 2026-07-14 · Single-seat Part 103 amphibious eVTOL · Target empty ≤ 115.2 kg (254 lb), chute + floats exempt

Masses are honest first-pass estimates. Cost is ballpark USD for one prototype. This is the list we buy from and weigh against.

## A. PROPULSION
| # | Part | Spec | Qty | Mass ea | Cost ea |
|---|---|---|-----|---|---|
| A1 | T-Motor U15XXL KV29 motor | 100 kg peak thrust, 24S | 4 | 4.2 kg | $1,999 |
| A2 | 62" (1575 mm) 2-blade CF prop | NS62×24 class | 4 | 1.2 kg | $420 |
| A3 | FLAME 300A HV ESC | 24S, potted for wet-side | 4 | 1.1 kg | $360 |
| A4 | Motor mount plate (CF/alu) | bolts motor to arm tip | 4 | 0.4 kg | $90 |
| | **Propulsion subtotal** | | | **27.6 kg** | **~$11,500** |

## B. STRUCTURE (the part that was "fishy" — now a real load path)
| # | Part | Spec | Qty | Mass ea | Cost ea |
|---|---|---|-----|---|---|
| B1 | Central spar box | 2 main + 2 cross CF spars, torque box under seat — ALL four arms + seat + gear bolt here | 1 | 14 kg | $2,200 |
| B2 | Arm boom | tapered CF tube, spar-box corner → motor | 4 | 2.4 kg | $340 |
| B3 | Arm brace strut | triangulates each boom to the box | 4 | 0.6 kg | $80 |
| B4 | Cockpit pod / monocoque | sealed CF tub (also the float), floor pan, windscreen frame | 1 | 22 kg | $3,500 |
| B5 | Helicopter skid gear | 2 CF rails + upswept toes + 4 struts | 1 | 6 kg | $600 |
| | **Structure subtotal** | | | **~54 kg** | **~$8,300** |

## C. ENERGY & AVIONICS
| # | Part | Spec | Qty | Mass | Cost |
|---|---|---|-----|---|---|
| C1 | 24S ~14 kWh Li-ion pack | high-discharge, in vented dry box | 1 | 58 kg | $9,000 |
| C2 | Battery mgmt + contactors | cell monitor, precharge, kill | 1 | 3 kg | $700 |
| C3 | **DIY triple-redundant flight ctrl** | 3× CubePilot Orange+ running ArduPilot/PX4 (open source), custom voting — built by us w/ AI, NOT bought proprietary | 3 | 0.8 kg | $300 ea |
| C4 | GNSS + IMU redundancy set | 2× GPS, air data (open-source stack) | 1 | 0.8 kg | $1,400 |
| C5 | Wiring, connectors (IP67) | wet-side sealed | — | 5 kg | $900 |
| | **Energy+avionics subtotal** | | | **~68 kg** | **~$13,200** |

> **Flight-control decision (Matt, 2026-07-14):** rejected the $18k proprietary Veronte. Software is free/open (ArduPilot flies millions of drones + full-size aircraft); we build our OWN triple-redundant controller from 3 cheap open boards + AI-written voting/tuning. Saves ~$16.8k. The redundancy (3 brains voting) is the part we KEEP — a single-controller hobby setup is fine for a $500 drone, fatal under a pilot. Part 103 needs zero certification, so we skip the cert-paperwork tax entirely. Real cost = ruthless TEST discipline (tether → ballast → manned), not license fees.

## D. COCKPIT & CONTROLS
| # | Part | Spec | Qty | Mass | Cost |
|---|---|---|-----|---|---|
| D1 | Seat + 4-point harness | composite pan | 1 | 5 kg | $600 |
| D2 | Sidestick + throttle | fly-by-wire inceptors | 1 | 1.5 kg | $1,200 |
| D3 | Instrument display | glass panel, sunlight-readable | 1 | 1 kg | $800 |
| D4 | Foot area / rudder pedals | yaw trim | 1 | 1 kg | $300 |
| | **Cockpit subtotal** | | | **8.5 kg** | **~$2,900** |

## E. SAFETY & THERMAL (chute is weight-EXEMPT under Part 103)
| # | Part | Spec | Qty | Mass | Note |
|---|---|---|-----|---|---|
| E1 | Ballistic parachute | whole-aircraft, rocket-deploy | 1 | 9 kg | **EXEMPT** — doesn't count |
| E2 | Battery cooling ducts + fans | NACA intakes, rear louvre exhaust | 1 | 2 kg | counts |
| E3 | Motor/ESC air scoops | dry-side airflow to arm roots | 4 | 0.2 kg | counts |
| E4 | Fire barrier / vent membrane | thermal-runaway venting overboard | 1 | 1.5 kg | counts |
| | **Safety+thermal (counted)** | | | **~4.3 kg** | |

## MASS ROLL-UP (the number that rules the project)
| Group | Counted mass |
|---|---|
| A Propulsion | 27.6 kg |
| B Structure | 54 kg |
| C Energy & avionics | 68 kg (now ~$13.2k, was $30k) |
| D Cockpit | 8.5 kg |
| E Thermal (counted) | 4.3 kg |
| **EMPTY WEIGHT (counted)** | **≈ 162 kg** |
| **PROTOTYPE PARTS COST** | **≈ $36,600** (incl. chute; after DIY flight-control saved ~$17k vs proprietary) |
| Part 103 limit | 115.2 kg |
| **OVER BY** | **≈ 47 kg** |
| (Exempt: chute 9 kg + any floats — not counted) | |

## THE WEIGHT WAR — where the 47 kg comes off
1. **Battery is 58 kg and the single biggest lever.** Jetson flies 20 min on ~60 kg, so we can't just delete it. A smaller pack (say 9 kWh / ~38 kg) buys back 20 kg at the cost of ~12 min flight — a real trade to put to Matt.
2. **Structure at 54 kg is heavy for carbon** — Jetson's whole airframe is 55 kg *including* 8 motor mounts. Aggressive CF layup + the spar-box doing double duty should reach ~40 kg (−14 kg).
3. **Avionics 68 kg is battery-dominated** — see #1.
4. **Honest verdict:** as-drawn it's ~47 kg over. Jetson proves ~253 lb is achievable, so the target is real — but it demands ruthless battery sizing + a featherweight airframe. This is THE engineering problem, and it's why milestone M0 is closing this spreadsheet before we cut carbon.

*Cross-refs: RESEARCH_REPORT_2026-07-13.md (Part 103 rules), RESEARCH_REPORT_ROUND2_2026-07-14.md (Jetson 55 kg airframe benchmark, battery Wh/kg).*

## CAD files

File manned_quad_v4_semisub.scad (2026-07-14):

// ============================================================
// MANNED QUAD eVTOL — V4 "SEMI-SUB" study (Matt's call: NO pontoons)
// The hull IS the flotation: semi-submersible stance, flared hard
// chines for roll stability, water-ballast tanks to squat low in
// boat mode and purge before takeoff (pump + valves, ~3 kg).
// Blades stay overhead; water propulsion = airboat mode on the lift
// props + optional stern pod. Rendered with waterline slab to show
// the semi-submerged stance. Units mm, Z up.
// ============================================================
$fn = 40;
rotor_plane = 2000;  rotor_dia = 1575;
WATERLINE = 260;     // semi-submerged: water sits at deck-chine level

// ---------- LOFTED HULL with flared chines (no pontoons) ----------
module hull_body() {
    color("ivory") hull() {
        translate([1290,0,160]) scale([1.0,0.55,0.7])  sphere(95);   // bow
        translate([700,0,190])  scale([1.0,1.0,0.75])  sphere(340);
        translate([0,0,210])    scale([1.05,1.35,0.80]) sphere(440); // chine flare
        translate([-800,0,200]) scale([1.0,1.25,0.78])  sphere(360); // chine flare
        translate([-1270,0,240]) scale([0.7,1.0,0.95])  sphere(220); // transom
        translate([0,0,-30])    scale([1.5,1.05,0.30])  sphere(440); // planing belly
    }
    color("dimgray") translate([100,0,-125]) rotate([45,0,0])
        cube([1900,140,140], center=true);
    // retractable beaching skids (land stance)
    color([0.2,0.2,0.2]) for (y=[-380,380]) for (x=[-620,620])
        translate([x,y,-215]) cylinder(h=170, d=46, center=true);
}

// ---------- CANOPY ----------
module canopy() {
    color("lightcyan",0.35) hull() {
        translate([250,0,780]) scale([1.25,0.85,1.0]) sphere(390);
        translate([880,0,500]) scale([1.0,0.75,0.8]) sphere(190);
    }
}

// ---------- GULL-WING ARMS + ROTORS ----------
function bez(t,p0,p1,p2) = [for(i=[0:2]) (1-t)*(1-t)*p0[i] + 2*(1-t)*t*p1[i] + t*t*p2[i]];
module gull_arm(fore, side) {
    root = [fore*480, side*430, 430];
    tip  = [fore*1025, side*1025, rotor_plane-60];
    ctrl = [fore*760, side*900, 920];
    pts  = [for(t=[0:0.084:1.001]) bez(t, root, ctrl, tip)];
    color("silver") for (i=[0:len(pts)-2]) hull() {
        translate(pts[i])   sphere(44 - 14*(i/(len(pts)-1)));
        translate(pts[i+1]) sphere(44 - 14*((i+1)/(len(pts)-1)));
    }
    mp = [fore*1025, side*1025, rotor_plane];
    color([0.13,0.13,0.13]) translate(mp) cylinder(h=95, d=150, center=true);
    color("gold") translate(mp) cylinder(h=99, d=118, center=true);
    color("black") translate([mp[0],mp[1],mp[2]+58]) rotate([0,0,fore*35+side*55])
        cube([rotor_dia,52,9], center=true);
    color("deepskyblue",0.10) translate([mp[0],mp[1],mp[2]+52])
        cylinder(h=3, d=rotor_dia, center=true);
}

// ---------- WATER BALLAST TANKS (squat low / purge to fly) ----------
module ballast() {
    color("cyan",0.55) for (y=[-300,300])
        translate([-350,y,20]) cube([700,160,180], center=true);
}

// ---------- INTERIOR / SYSTEMS ----------
module battery()  { color("orange",0.85) translate([-100,0,90])  cube([600,380,240], center=true); }
module avionics() { color("green",0.9)   translate([430,0,200])  cube([220,260,140], center=true); }
module seat() {
    color([0.05,0.05,0.05]) translate([120,0,330]) cube([430,470,40], center=true);
    color([0.05,0.05,0.05]) translate([-100,0,620]) rotate([0,-12,0]) cube([40,470,620], center=true);
}
module chute()    { color("crimson") translate([-680,0,580]) cylinder(h=240, d=170, center=true); }
module stern_pod() {
    color("navy") translate([-1360,0,-60]) rotate([0,90,0]) cylinder(h=280, d=115, center=true);
    color("black") translate([-1515,0,-60]) rotate([0,90,0]) cylinder(h=8, d=220, center=true);
}

// ---------- WATER (semi-submerged stance visual) ----------
module water() {
    color([0.12,0.38,0.55,0.45]) translate([0,0,WATERLINE-1500])
        cube([9000,9000,3000], center=true);
}

// ---------- ASSEMBLY ----------
// Matt 2026-07-13: like the RC waterproof drones (SwellPro class) —
// land IN the water, float naturally low on the sealed hull, take off
// straight from the surface. PASSIVE buoyancy sets the waterline
// (220 kg needs 220 L submerged; this hull has ~3x that volume, so it
// floats with roughly the bottom third wet — same stance as the RC
// ones). Ballast tanks deleted: not needed, the drones don't have them.
hull_body(); canopy();
for (f=[-1,1]) for (s=[-1,1]) gull_arm(f, s);
battery(); avionics(); seat(); chute(); stern_pod();
water();

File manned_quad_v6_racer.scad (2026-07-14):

// ============================================================
// MANNED QUAD eVTOL — V6 "RACER TUB" (Matt: fuselage was weird,
// wants racing-drone look). Racing quads = low, tight, ANGULAR
// carbon monocoque: faceted wedge tub, raked low canopy, nothing
// bulbous. Keeps everything already approved:
//   - trussed arms (straight boom + diagonal brace)
//   - rotor plane 1400 mm (just above the cockpit)
//   - helicopter skids w/ upswept noses, ~0.4 m clearance
//   - sealed belly (can land on water & take off, SwellPro-style)
// Units mm, Z up.
// ============================================================
$fn = 40;
rotor_plane = 1400;
rotor_dia   = 1575;

module boom(p1, p2, r1, r2) {
    hull() { translate(p1) sphere(r1); translate(p2) sphere(r2); }
}

// ---------- ANGULAR RACING TUB (faceted carbon wedge) ----------
module tub() {
    color([0.16,0.17,0.19]) hull() {                       // carbon lower tub
        translate([1050,0,140]) rotate([0,18,0]) cube([340,300,150], center=true); // wedge nose
        translate([420,0,170])  cube([620,640,260], center=true);
        translate([-250,0,190]) cube([700,660,300], center=true);
        translate([-850,0,210]) rotate([0,-7,0]) cube([420,440,240], center=true);
        translate([-1180,0,260]) cube([150,280,170], center=true);  // tail
    }
    color("ivory") hull() {                                 // top deck panel
        translate([500,0,330])  cube([500,540,60], center=true);
        translate([-350,0,360]) cube([620,560,70], center=true);
        translate([-1150,0,330]) cube([120,240,50], center=true);
    }
}

// ---------- LOW RAKED CANOPY (racing pod) ----------
module canopy() {
    color("lightcyan",0.38) hull() {
        translate([620,0,420])  rotate([0,22,0]) cube([340,430,40], center=true); // windscreen
        translate([90,0,700])   cube([340,430,60], center=true);                  // crown
        translate([-450,0,560]) rotate([0,-18,0]) cube([420,430,50], center=true);// fastback
    }
}

// ---------- TRUSSED ARMS (approved) ----------
module truss_arm(f, s) {
    mp   = [f*1025, s*1025, rotor_plane];
    high = [f*430,  s*330, 420];
    low  = [f*660,  s*420, 160];
    mid  = [f*760,  s*740, 1000];
    color("silver") {
        boom(high, [mp[0], mp[1], mp[2]-60], 42, 30);
        boom(low,  mid, 26, 22);
    }
    color("silver") translate(high) sphere(52);
    color([0.13,0.13,0.13]) translate(mp) cylinder(h=95, d=150, center=true);
    color("gold") translate(mp) cylinder(h=99, d=118, center=true);
    color("black") translate([mp[0],mp[1],mp[2]+58]) rotate([0,0,f*35+s*55])
        cube([rotor_dia,52,9], center=true);
    color("deepskyblue",0.10) translate([mp[0],mp[1],mp[2]+52])
        cylinder(h=3, d=rotor_dia, center=true);
}

// ---------- HELICOPTER SKIDS (approved) ----------
module skids() {
    color([0.15,0.15,0.15]) for (s=[-1,1]) {
        translate([-100, s*440, -480]) rotate([0,90,0])
            cylinder(h=2100, d=55, center=true);
        boom([950, s*440, -480], [1300, s*440, -300], 27, 24);
        for (x=[-560,560])
            boom([x, s*300, 20], [x, s*440, -465], 26, 24);
    }
}

// ---------- SYSTEMS ----------
module battery()  { color("orange",0.85) translate([-150,0,120]) cube([600,380,220], center=true); }
module avionics() { color("green",0.9)   translate([430,0,190])  cube([220,260,130], center=true); }
module seat() {
    color([0.05,0.05,0.05]) translate([120,0,300]) cube([430,460,40], center=true);
    color([0.05,0.05,0.05]) translate([-110,0,560]) rotate([0,-14,0]) cube([40,460,560], center=true);
}
module chute() { color("crimson") translate([-780,0,430]) cylinder(h=200, d=160, center=true); }

// ---------- ASSEMBLY ----------
tub(); canopy(); skids();
for (f=[-1,1]) for (s=[-1,1]) truss_arm(f, s);
battery(); avionics(); seat(); chute();

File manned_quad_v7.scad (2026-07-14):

// ============================================================
// MANNED QUAD eVTOL — V7 "REALISTIC STRUCTURE"
// Fixes Matt's notes (2026-07-14): arms/motor mounts looked
// fishy + cockpit "how would it work" + wants venting/airflow.
//
// REAL LOAD PATH: a central CF SPAR BOX carries everything —
// all 4 arms bolt to its 4 corners, the seat sits on it, the
// skids hang off it. Arms = tapered boom + brace to the SAME box
// (a true triangle to a real hardpoint, not poking into skin).
// Cockpit = open tub w/ floor pan, seat, panel, windscreen.
// COOLING: NACA side intakes -> battery box -> rear louvre
// exhaust; small scoops feed ESCs at the arm roots.
// Units mm, Z up. See PARTS_LIST_BOM.md for the matching BOM.
// ============================================================
$fn = 44;
rotor_plane = 1400;
rotor_dia   = 1575;
box_x = 1000;  box_y = 720;  box_z = 260;   // spar box
box_h = 250;                                 // box floor height

module boom(p1,p2,r1,r2){ hull(){ translate(p1) sphere(r1); translate(p2) sphere(r2); } }

// ---------- CENTRAL SPAR BOX (the real structure) ----------
module spar_box() {
    color([0.20,0.21,0.24]) {
        // 2 main spars (fore-aft) + 2 cross spars = torque box
        for (y=[-box_y/2, box_y/2])
            translate([0,y,box_h]) rotate([0,90,0]) cylinder(h=box_x,d=70,center=true);
        for (x=[-box_x/2, box_x/2])
            translate([x,0,box_h]) rotate([90,0,0]) cylinder(h=box_y,d=70,center=true);
        // corner hardpoint lugs (where arms bolt on)
        for (x=[-box_x/2,box_x/2]) for (y=[-box_y/2,box_y/2])
            translate([x,y,box_h]) sphere(60);
        // floor pan spanning the box
        translate([0,0,box_h-40]) cube([box_x+40,box_y+40,24],center=true);
    }
}

// ---------- ARM: boom + brace, both to the SAME corner lug ----------
module arm(f,s) {
    corner = [f*box_x/2, s*box_y/2, box_h];       // real hardpoint
    mp     = [f*1025,    s*1025,    rotor_plane];  // motor
    brace0 = [f*box_x/2*0.2, s*box_y/2*0.2, box_h+30]; // inboard box node
    color("silver") {
        boom(corner, [mp[0],mp[1],mp[2]-55], 40, 30);   // main boom
        boom(brace0, [ (corner[0]+mp[0])/2,(corner[1]+mp[1])/2,(corner[2]+mp[2])/2 ], 24, 20); // brace to mid-boom
        translate(corner) sphere(46);                    // bolted gusset
    }
    // ESC pod + cooling scoop at arm root
    color([0.12,0.12,0.13]) translate(corner+[f*60,s*60,60]) cube([150,90,80],center=true);
    color([0.3,0.5,0.7,0.6]) translate(corner+[f*140,s*60,60]) rotate([0,90,0]) cylinder(h=40,d=48,center=true);
    // motor U15XXL + prop
    color([0.13,0.13,0.13]) translate(mp) cylinder(h=95,d=150,center=true);
    color("gold") translate(mp) cylinder(h=99,d=118,center=true);
    color([0.9,0.9,0.9]) translate(mp+[0,0,52]) cylinder(h=14,d=60);   // prop hub
    color("black") translate(mp+[0,0,60]) rotate([0,0,f*35+s*55]) cube([rotor_dia,52,9],center=true);
    color("deepskyblue",0.10) translate(mp+[0,0,54]) cylinder(h=3,d=rotor_dia,center=true);
}

// ---------- COCKPIT TUB (open, with floor / panel / windscreen) ----------
module cockpit() {
    // sealed lower tub (also the float) around & below the spar box
    color([0.16,0.17,0.19]) hull() {
        translate([980,0,box_h-30]) rotate([0,16,0]) cube([300,360,150],center=true); // nose wedge
        translate([300,0,box_h-10]) cube([620,box_y+120,230],center=true);
        translate([-450,0,box_h])   cube([560,box_y+80,250],center=true);
        translate([-1050,0,box_h+40]) cube([160,300,180],center=true);                // tail
    }
    // seat (on the floor pan)
    color([0.05,0.05,0.05]) translate([90,0,box_h+120]) cube([440,460,40],center=true);
    color([0.05,0.05,0.05]) translate([-140,0,box_h+380]) rotate([0,-14,0]) cube([40,460,540],center=true);
    // instrument panel + sidestick
    color([0.1,0.1,0.12]) translate([430,0,box_h+230]) rotate([0,-28,0]) cube([40,440,220],center=true);
    color([0.7,0.05,0.05]) translate([430,0,box_h+230]) rotate([0,-28,0]) translate([22,0,0]) cube([6,300,120],center=true);
    color([0.2,0.2,0.22]) translate([250,-180,box_h+150]) cylinder(h=140,d=30);        // stick
    // windscreen + low canopy rails (open cockpit racer)
    color("lightcyan",0.32) hull() {
        translate([560,0,box_h+300]) rotate([0,26,0]) cube([300,440,30],center=true);
        translate([120,0,box_h+520]) cube([300,440,40],center=true);
        translate([-380,0,box_h+380]) rotate([0,-16,0]) cube([360,440,30],center=true);
    }
}

// ---------- COOLING: NACA side intakes + rear exhaust louvres ----------
module cooling() {
    // NACA-style flush intakes on the tub sides -> battery box
    color([0.05,0.15,0.30,0.8]) for (s=[-1,1])
        translate([250, s*(box_y/2+65), box_h]) rotate([0,0,s*90])
            scale([1,0.5,1]) cylinder(h=8,d=150,center=true);
    // rear exhaust louvres
    color([0.05,0.15,0.30,0.8]) for (i=[0:3])
        translate([-980, 0, box_h-40+i*45]) rotate([0,70,0]) cube([90,300,8],center=true);
    // battery inside the box (vented dry box)
    color("orange",0.85) translate([-80,0,box_h+10]) cube([620,box_y-120,200],center=true);
}

// ---------- HELICOPTER SKIDS (hang off the spar box) ----------
module skids() {
    color([0.14,0.14,0.14]) for (s=[-1,1]) {
        translate([-80,s*430,box_h-620]) rotate([0,90,0]) cylinder(h=2050,d=55,center=true);
        boom([920,s*430,box_h-620],[1260,s*430,box_h-450],27,24);
        for (x=[-box_x/2*0.8, box_x/2*0.8])
            boom([x,s*box_y/2, box_h-40],[x,s*430,box_h-605],26,24);
    }
}

module chute(){ color("crimson") translate([-820,0,box_h+250]) cylinder(h=200,d=150,center=true); }

// ---------- ASSEMBLY ----------
spar_box();
cockpit();
cooling();
for (f=[-1,1]) for (s=[-1,1]) arm(f,s);
skids();
chute();

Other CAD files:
manned_quad_v2.scad
manned_quad_v3.scad
manned_quad_v5.scad

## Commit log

2026-07-14 Open-source the Sky Tribe amphibious eVTOL project
    Full open-hardware release: CAD (v2-v7), bill of materials, three
    fact-checked research reports, interactive viewer, mission, and
    contributor guide.
    Licenses (chosen so it can never be locked up):
    - Hardware/CAD: CERN-OHL-S-2.0 (strongly reciprocal)
    - Software: GPL-3.0-or-later (built on ArduPilot/PX4)
    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
    [manned_quad_v2.scad, manned_quad_v3.scad, manned_quad_v4_semisub.scad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]
2026-07-14 Add interactive build viewer + drop water-landing requirement
    - sky_tribe_viewer.html: real-time 3D model, click any part for its
    price/mass/spec, explode slider, 'look into cockpit' camera, pilot
    figure for scale, live parts-total (~$36.6k).
    - Water-landing dropped per design decision (lighter, no sealing mass).
2026-07-14 Add waterproofing + cargo bay; correct prototype cost to ~$36.6k
    - Cockpit tub now a sealed WATERPROOF shell (rain/spray rated).
    - Added ~60 L cargo bay behind the seat for minimal cargo.
    - BOM: honest prototype parts cost ~$36,600 (DIY flight control still
    saved ~$17k vs the proprietary box).
2026-07-14 Cockpit is now an enclosed cabin: glass canopy + walls + bulkhead
    Was an open seat on a solid lower shell. Now a sealed waterproof cabin:
    side walls, rear bulkhead, footwell front, aero nose, and a transparent
    glass canopy dome + windscreen with frame rails over the pilot.
2026-07-14 Sink pilot into hull + add water mode with computed waterline
    - Pilot now sits DOWN in the hull (hips at keel, feet forward, knees up,
    canopy over head) instead of perched on top of the spar deck.
    - Water mode toggle: shows the computed waterline. All-up ~241 kg floats
    with ~20 cm of belly submerged, ~2.7x reserve buoyancy, cabin dry.
    - WATER_STANCE.md documents the buoyancy math.
2026-07-14 Rework CAD: framed fighter canopy, clear waterline, openable cargo hatch; remove AI renders
    - Framed canopy: carbon space-frame over the glass (sill rails, 3 cross
    bows, top spine, rear hinge, front latch) — openable, not a bubble.
    - Water mode: bright cyan waterline ring marks exactly where the hull
    sits in the water (was hard to see before).
    - Cargo bay: hinged top hatch shown open with a handle — actually
    accessible now.
    - Default view = 3/4; removed concept_render PNGs (didn't match the CAD).
2026-07-14 Rebuild fuselage as ONE smooth lofted silhouette + integrated framed canopy
    Root-cause fix for the 'two ovals' look: fuselage is now a single lofted
    surface (cross-section stations nose->tail with a natural canopy hump),
    not a belly-blob + canopy-blob. Canopy glass follows the same silhouette;
    the frame OUTLINES the canopy opening (sill + windscreen + spine + rear
    hinge + latch) instead of caging the pilot. Solid body shown by default;
    x-ray now optional.
2026-07-14 Battery down into keel + realistic color; open cargo well; canopy extended over cargo
    - Battery moved low into the keel (was at waist height overlapping the
    pilot in x-ray) and recolored dark graphite instead of glowing orange
    — looks real, and low CG is correct anyway.
    - Rear compartment is now an OPEN cargo well (floor + low lips, open to
    cabin) for a dog / groceries — not a sealed box.
    - Canopy glass + frame extended back to cover the cargo area (one
    greenhouse over the whole cabin).
2026-07-14 Add retractable hydrofoils + water motor to CAD; clearer see-through glass
    - Hydrofoils: main forward foil (under CG) + rear stabilizer on carbon
    masts that drop below the skids, plus a water torpedo motor + prop.
    Toggle to deploy/retract. Part card explains foiling + active flaps.
    - Glass: more transparent + wider wrap so you can see the pilot through
    it; clearly reads as glass vs the lighter carbon body.
2026-07-14 Foil wing IS the skid (one gear, not both) + open-canopy option
    - Removed separate helicopter skids. The hydrofoil wings now ARE the
    landing gear: rest on them like skis on land, foil on them in water.
    Main foil-ski (fwd, under CG) + rear stabilizer, water motor pod.
    - Open-canopy toggle: canopy glass + frame hinge up at the rear.
    - See-through glass so the pilot shows through the canopy.
2026-07-14 Cut real cockpit opening so open canopy reveals interior; spread foil-skis wide
    - Hull top is now OPEN across the cockpit/cargo region (loft skips top
    faces there), so lifting the canopy reveals the pilot, seat, and
    controls instead of solid body. Fixes 'can't see inside when open'.
    - Foil-skis spread far apart fore-aft (main forward, rear far back) for
    a stable landing stance that won't tip.
2026-07-14 Bigger wing-tip landing feet so the motor prop clears the ground
    The small tip end-plates let the water-motor prop hang below them — it
    would strike the ground on a hard landing. Enlarged them into proper
    end-plate feet that extend well below both the wing and the prop, so the
    craft rests on the four feet and the fan stays clear (they double as
    hydrofoil tip fins in the water).
2026-07-14 Add hydrofoil research report (round 4): sizing, self-stable V-foils, takeoff hump
    Verified findings: ~0.15-0.20 m2 total foil lifts 240 kg at ~15 kt;
    fixed inverted-V surface-piercing foils self-balance with no controller
    (best for Part 103); takeoff needs ~3-4x cruise power (the real
    constraint); foil-strut-ending-in-a-skid-foot is UNPROVEN prior art
    (our novel piece); floating remains legit, foiling is a Phase-2 upgrade.
2026-07-16 Move to coax X8, add P1/P2 two-prototype configs, land round-5 research
    Architecture change — quad -> coaxial X8 (8 motors, 4 arms):
    A flat quad has no motor-out capability: any single motor or ESC failure
    leaves the aircraft uncontrollable. Round-5 research confirms it — a
    single-rotor failure on a quad is classed catastrophic, quads showed the
    highest failure rate of the VTOL configs studied, and independent analyses
    conclude at least eight rotors is what satisfies motor-out safety. Each arm
    tip now carries two counter-rotating motors + props with independent ESCs,
    so a dead motor only weakens its corner instead of killing it.
    Also from round 5, corrected against the literature:
    - coa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
2026-07-16 Photoreal render upgrade, rear bulkhead, presentation mode + video
    Rendering: ACES filmic tone mapping, image-based lighting (RoomEnvironment
    + dusk gradient the carbon/glass actually reflect), three-point lights with
    soft shadows. Materials rebuilt physically — carbon is now non-metal with a
    clearcoat and a woven normal map, the canopy uses real glass transmission
    instead of fade-out opacity, metals get proper env reflection.
    Geometry fixes Matt caught on inspection:
    - rear bulkhead behind the pilot — the cockpit opening had nothing closing it
    off aft, so the back view looked straight down the empty fuselage. Also
    what makes the "sealed shell" real for a water landing.
    - canopy/hul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
2026-07-16 Route arms clear of the canopy, add an automated geometry audit
    The arms ran into the canopy glass. Root cause: the booms started inboard on
    the spar box (under the cockpit) and climbed to a rotor plane above the canopy,
    so they had to cross the canopy's footprint to get there. Straightening or
    re-bracing could never fix that — the path itself was wrong.
    Booms are now dog-legged: they run outboard first, low and below the canopy
    sill, until they are clear of the glass half-width (elbow at 820mm vs a 450mm
    widest half-width, so 370mm of margin), and only then climb to the motors.
    The braces that used to stand up through the cockpit are gone; each boom is now
    braced from below by a strut of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
2026-07-16 Restore 62in props on the X8 and fair the ESC pods
    The X8 conversion shrank the props from 62in to 54in on the reasoning that
    "there are eight discs now". That reasoning was wrong: a coaxial pair stacks two
    props on ONE axis, so the X8 still has four disc locations, and the arm spacing
    never changed. The smaller prop threw away 24% of disc area for nothing —
    hover power went from ~46 kW to ~53 kW at P1's 261 kg all-up, and disk loading
    from 33 to 44 kg/m², which is endurance we were paying for with no benefit.
    62in fits with room to spare: 476mm clear between adjacent discs and 663mm of
    tip reach against a 465mm body half-width. Coax spacing raised 350mm -> 400mm
    because the round-5 rule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
2026-07-16 Fix the cockpit: level sill, canopy cut from the hull itself, real visibility
    The pilot could not see out. The hull opening was cut by ANGLE (skip faces above
    30 degrees), so the sill followed the ellipse and climbed to y=770 at the widest
    station — 42mm ABOVE the pilot's 728mm eye line. You were looking at the inside
    of the fuselage. It also made the sill a curve that swept up over the shoulder
    instead of a line.
    The cut is now at a constant world height (y=600), which does two things: the
    sill is a straight, level coaming down each side, and the eye sits 128mm above
    it, just under shoulder height, like a real cockpit.
    The canopy was a separate loft with its own station list — differe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
2026-07-16 Reshape the hull, recline the pilot, and fix parts hanging outside the aircraft
    The body read as a blob with a bubble stuck on top because every station was a pure
    ellipse — an ellipse pinches to nothing at the keel and bulges hardest at mid-height,
    so there was no shoulder for the canopy to grow out of and no usable width down where
    the battery lives. Stations are now superellipses (SE=3), which keeps the envelope but
    flattens the belly and sides. The body is also longer and narrower: 3050 x 760mm, a
    fineness ratio of 4.0 against the old 2.8. The canopy now grows out of a wide flat
    shoulder as one line from nose to tail.
    Fixed, all found by measuring rather than looking:
    - The pilot's FE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
2026-07-16 Show the renders on the repo page and bring the README up to date
    The README still described a 4-rotor quad with 25 kW hover and a 47 kg overage —
    none of which has been true for several commits. It now shows the aircraft (side,
    front and back renders on the front page) and describes what actually exists: the
    coax X8, the two-configuration program, and the numbers that do not close yet.
    Corrected while writing it: the panel claimed a 14 kWh pack, but the pack that
    actually fits the keel is 52 L, so ~13 kWh. Endurance claims followed from the
    old 25 kW hover figure and were far too optimistic — at the real ~46 kW, P1 gets
    ~14 min hover / ~21 min cruise, not 35-40. P2 gets ~11 min cruise.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
2026-07-17 Correct the endurance and speed numbers; publish the performance model
    Two errors in my own performance maths, both of which made the aircraft look
    better than it is:
    * Induced and profile power were being divided by Figure of Merit — but FoM
    already accounts for profile losses, so profile was counted twice.
    * Shaft power was quoted as if it were battery draw. The battery pays
    electrical power: shaft / (motor x ESC efficiency).
    Corrected, the honest numbers are worse than the README claimed:
    P1 hover 52.4 kW -> 11.9 min; max flight time 15.1 min; max range 15.0 mi
    P2 hover 37.6 kW -> 6.4 min; max flight time 7.9 min; max range 6.6 mi
    Top speed is set by the roto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
2026-07-17 Purge the stale numbers from the presentation and part cards
    The narrated tour and several part cards still carried figures the performance
    model has since disproved: 14 kWh (the pack that fits is 13), "35-40 min cruise"
    (it is 15 minutes), "30-60 min" for the swap bay, and "75-80 mph" for the pusher.
    The pusher card also repeated the claim that it protects forward visibility. That
    was wrong: pitching nose-down rotates the pilot's whole sight cone down with the
    airframe, so a leaning multirotor sees more ground ahead, not less. The pusher
    buys a level cruise attitude and efficiency — not speed, and not visibility. The
    top speed ceiling is set by rotor advance ratio (~67 mph), not by power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
2026-07-17 Fix a broken apostrophe that stopped the viewer loading
    The previous commit put an unescaped apostrophe inside a single-quoted string,
    which is a syntax error — the whole module failed to parse and the CAD rendered
    nothing. It was pushed in that state.
    Verified this time by actually loading the page and rendering a frame, not just
    by reading the diff. Audit 20/20, viewer renders.
2026-07-17 Add P3 — the hybrid. Same airframe, fuel instead of a battery.
    Part 103 counts the machinery against the 254 lb limit but does not count the
    fuel. That one line is the whole argument: 5 gallons is 14 kg and 172 kWh of
    thermal energy, which at a realistic 25% genset efficiency is ~43 kWh electrical
    against the 13 kWh in the battery. The genset, buffer and fuel system add up to
    62 kg of counted weight against the battery's 58 — so +4 kg buys 3.5x the energy,
    and endurance goes from 15 minutes to 49 minutes hovering, 62 cruising.
    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
2026-07-17 Stop the instrument panel punching out through the windscreen
    The panel sat at the very front of the cockpit opening, where the body has already
    tapered to a roof of about 618mm — so its top corner stood 42mm proud of the glass,
    and the display 26mm. Moved aft and down to where there is actually room under the
    canopy.
    interior_audit.mjs now checks every interior fitting against the body surface at its
    own station, the same lesson as the battery: check a part where it actually is, not
    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
2026-07-17 Correct the hybrid's weight: +34 kg, not +4 kg
    I claimed the hybrid cost only 4 kg more than the battery it replaces. That was
    wrong, and wrong in the flattering direction. The figure counted a 44 kg "genset"
    as though it covered the whole system — but a salvage snowmobile engine ALONE is
    about 42 kg, and the radiator, rectifier, engine mounts, exhaust, ECU and fuel
    system were simply missing from the count.
    The honest system is 92 kg against 58 kg of battery: +34 kg and +$2,500
    ($11,500 vs $9,000). P3 empty is 210 kg, not 181. All-up goes to 309 kg, so the
    hybrid needs 70 kg/motor to fly at all — at 60 it is 1.33 and does not.
    The case still stands on its merits: 12 minutes of hover b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
2026-07-17 Publish the real project cost, not just the parts list
    The parts list and the project are not the same number and it was misleading to
    only ever quote the first. One aircraft is ~$46,600 in parts. Getting that
    aircraft to actually fly is ~$82,600, because a parts list silently omits the
    thrust stand, the tether rig, carbon moulds and consumables, machining, wiring
    and HV safety gear, telemetry, spares, and a crash allowance for the two
    milestones whose entire purpose is to break things. The whole program, P1 through
    P2 with a genset conversion, is ~$139,700 with labour at zero.
    Also worth stating plainly: the cheapest useful spend is ~$5,300 — one motor, one
    prop, one ESC and a thrust sta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
2026-07-17 Spell out the build order: platform first, cockpit last
    Worth stating plainly, because "build the aircraft" sounds like one job and is not.
    M2 and M3 are unmanned and ballasted, so nothing that exists for a person is needed
    to prove the machine hovers. The cockpit tub, canopy, seat, panel, ballistic chute,
    hydrofoil gear and pusher come to $18,100 that can be deferred until after thousands
    of unmanned cycles.
    The order that falls out: $5,300 to ask whether the motor makes its number, then
    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
2026-07-25 Clear out the superseded flat-quad renders
    Thirteen PNGs from the v3–v7 OpenSCAD studies were still sitting in the repo root
    alongside the current X8 renders, with no README or script pointing at any of them.
    They show a flat four-motor machine with skids — a configuration the project
    abandoned once the motor-out case ruled out anything under eight rotors — so anyone
    opening the folder met a dozen pictures of an aircraft we are not building.
    quad_v2_viewer.html goes with them; sky_tribe_viewer.html replaced it and the file
    had already been removed from the working tree.
    The .scad sources stay. They are the design history the README points to, and they
    are text — it is the pictures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
2026-10-22 README: pin image URLs to commit
